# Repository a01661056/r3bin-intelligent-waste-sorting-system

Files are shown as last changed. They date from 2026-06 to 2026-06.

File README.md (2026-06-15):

# R3Bin: Intelligent Waste Sorting System








R3Bin is a complete physical prototype designed to automate waste classification through embedded control, local computer vision, real-time actuation, and custom mechanical sorting. It identifies, sorts, and stores waste objects by integrating an ATmega16 real-time controller, a Raspberry Pi 5 computer-vision subsystem, TensorFlow Lite image classification, UART communication, I2C/TWI communication, EEPROM persistence, MG996R servo control, NEMA 17 stepper motor positioning, sensors, a custom user interface, and a physical structure manufactured through 3D printing and laser-cut fabrication.

R3Bin is not a simulation, mockup, or CAD-only concept. It combines embedded firmware, computer vision, AI inference, mechanical design, manufacturing, real-time control, and hardware/software integration into a functioning system that was built, assembled, calibrated, tested, and demonstrated as a working prototype.

**Demo:** [R3Bin final demo video](https://youtu.be/eC5EfTwEhFM)

## Technologies

| Domain | Technologies |
| --- | --- |
| Embedded control | ATmega16, AVR-GCC, direct register-level C firmware, GPIO, ADC |
| Computer vision | Raspberry Pi 5, Logitech C270 webcam, OpenCV |
| AI inference | TensorFlow Lite / LiteRT, Teachable Machine exported model |
| Communication | UART serial protocol, I2C/TWI bus |
| Persistence | ATmega16 EEPROM for game high score and per-category statistics |
| Actuation | PCA9685 PWM driver, MG996R servos, NEMA 17 stepper motor |
| Motor control | DRV8825 stepper driver, KW11 homing switch, calibrated sector positioning |
| User interface | 16x2 LCD, category LEDs, potentiometer, push buttons, active buzzer |
| Mechanical design | ForgeCAD, 3D printing, laser-cut PVC/acrylic, PETG/PLA parts, styrene dividers |

## Project Visuals

### Complete Physical Prototype

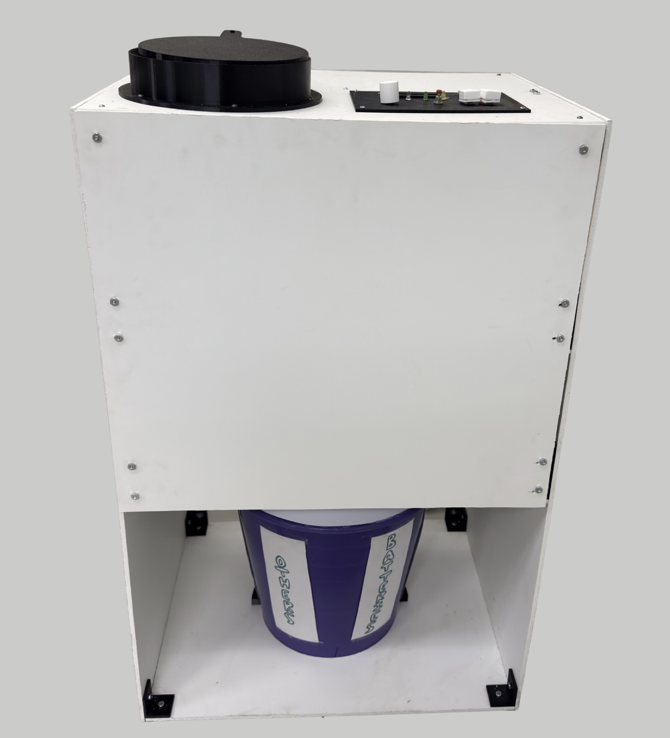
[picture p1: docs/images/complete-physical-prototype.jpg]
Complete physical R3Bin prototype


Complete assembled R3Bin prototype with the user-facing interface, inlet mechanism, PVC/acrylic structure, and storage body.

### Internal Mechanism Through Acrylic

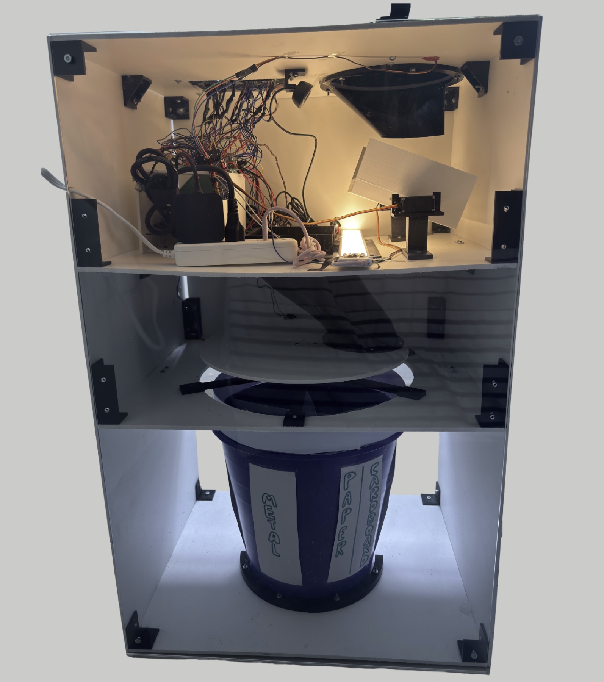
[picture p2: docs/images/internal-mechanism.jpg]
Internal R3Bin mechanism through acrylic


Rear acrylic view showing the internal sorting path, actuation mechanisms, rotating disk area, and storage region.

### Waste Sorting Process

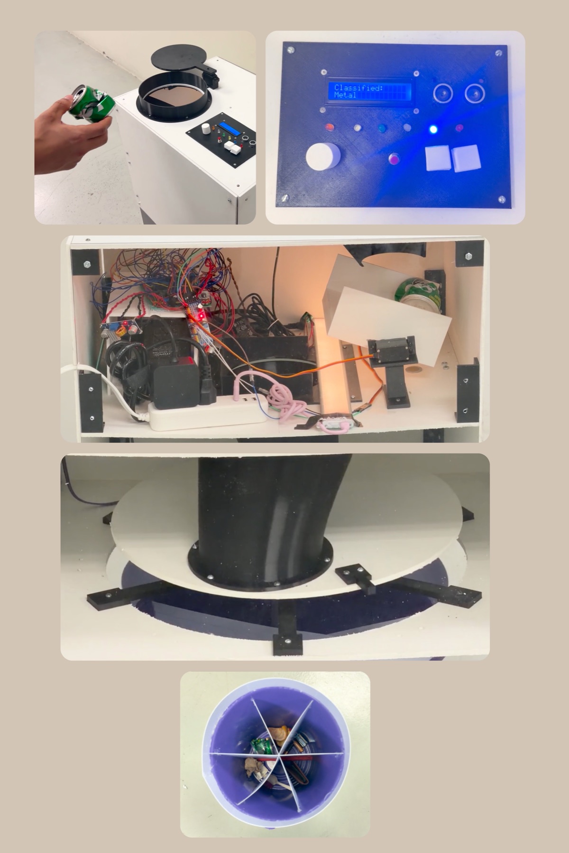
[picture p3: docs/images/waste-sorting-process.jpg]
R3Bin waste sorting process collage


End-to-end sorting sequence from object insertion and photo booth capture to classification, disk positioning, and storage.

### User Interface and Embedded Control

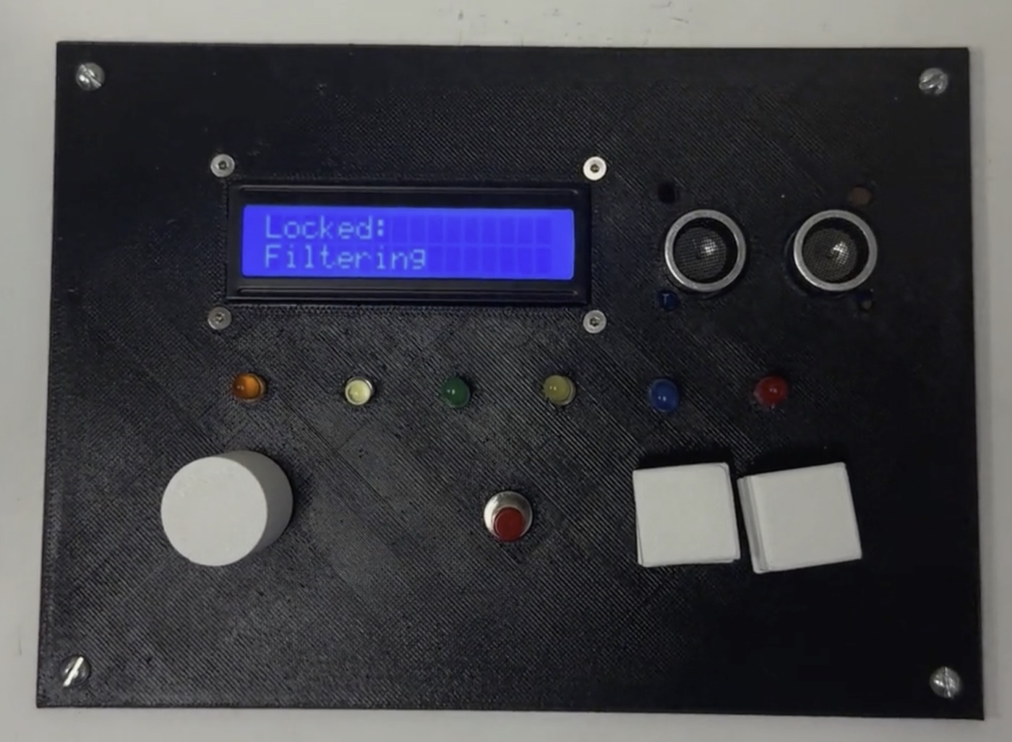
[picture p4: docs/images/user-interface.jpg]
R3Bin user interface


User-facing control panel with LCD feedback, mode selector, category LEDs, buttons, and ultrasonic detection.

### CAD Model vs Physical Build

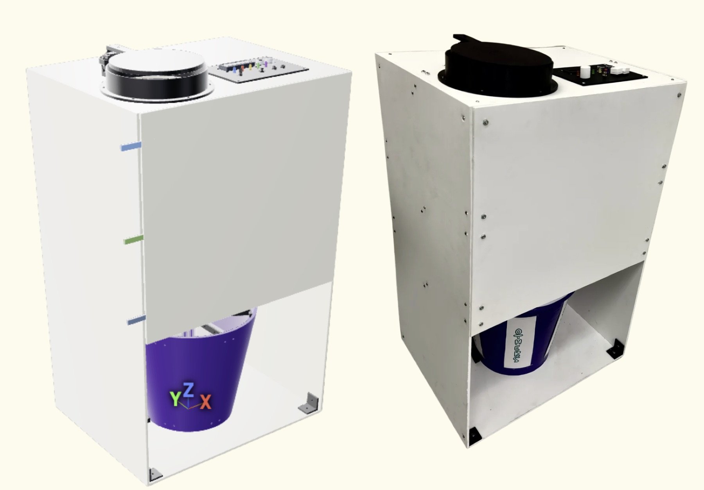
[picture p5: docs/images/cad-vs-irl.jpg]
R3Bin CAD model vs physical build


ForgeCAD model compared with the final physical prototype, showing the transition from parametric design to manufactured system.

## Overview

R3Bin automates the full waste-sorting cycle:

1. A user selects an operating mode with a potentiometer.
2. An ultrasonic sensor detects the user's hand and locks the selected mode.
3. A servo-driven inlet lid opens and receives one object.
4. The object enters an internal photo booth.
5. The ATmega16 requests image classification from the Raspberry Pi 5 over UART.
6. The Raspberry Pi captures an image with a Logitech C270 webcam and runs a TensorFlow Lite model locally.
7. The Raspberry Pi returns the detected category to the ATmega16.
8. The ATmega16 drives the NEMA 17 sorting disk to the selected sector.
9. Servo mechanisms release the object into the matching storage compartment.
10. EEPROM-backed counters and game high score are updated.

The final prototype classifies waste into six categories:

- Other
- Plastic
- Paper/cardboard
- Metal
- Organic
- Batteries

## Key Contributions

- Built a complete hardware/software system combining embedded firmware, AI inference, mechanisms, and physical manufacturing.
- Implemented real-time control logic on an ATmega16 using C, direct register configuration, UART, I2C/TWI, ADC, EEPROM, GPIO, and timing routines.
- Integrated Raspberry Pi 5 computer vision using OpenCV, TensorFlow Lite, and a locally trained Teachable Machine model.
- Designed and calibrated actuator sequences for MG996R servos, a PCA9685 PWM driver, a NEMA 17 stepper motor, and a DRV8825 stepper driver.
- Developed ForgeCAD parametric models, 3D-printable parts, laser-cut PVC/acrylic layouts, and physical assembly strategy.
- Validated the complete system with timing, energy, capacity, and classification measurements.

## My Role

My primary contributions focused on embedded systems integration, firmware architecture, hardware interfacing, and system-level integration. I worked on connecting the ATmega16 controller, Raspberry Pi vision subsystem, communication interfaces, and electromechanical sorting mechanisms into a complete working prototype. A major part of my work was making the independent subsystems operate together reliably as a single physical system.

This included work on UART communication, I2C/TWI communication, ATmega16 firmware, EEPROM persistence, operating-mode logic, actuator control, sensor integration, testing, debugging, calibration, and system-level integration between the microcontroller, Raspberry Pi, computer vision subsystem, and mechanical mechanisms.

Specific areas of ownership included:

- ATmega16 firmware structure and mode-state logic.
- UART protocol between ATmega16 and Raspberry Pi.
- PCA9685 servo control through I2C/TWI.
- EEPROM persistence for statistics and game high score.
- Potentiometer mode selection through ADC.
- LCD/LED user-feedback logic.
- NEMA 17 homing and sector positioning with the KW11 switch.
- Physical calibration of servos, disk movement, object release, and timing.
- Integration testing across firmware, camera classification, motors, and mechanical structure.

## Collaboration

R3Bin was developed as a team project rather than a solo build.

Team members:

- Ricardo Morán Ávila
- Joaquín Ruenes Hernández
- Rafael Tello Arenas

All team members contributed to the final prototype across design, manufacturing, assembly, testing, documentation, and demonstration.

## System Architecture

R3Bin separates responsibilities across real-time control, AI inference, user interaction, and mechanical execution.

| Subsystem | Responsibility |
| --- | --- |
| ATmega16 real-time controller | Main state machine, mode logic, actuator sequencing, LCD/LED updates, EEPROM storage, sensor polling |
| Raspberry Pi 5 vision subsystem | Camera capture, TensorFlow Lite inference, label normalization, UART response |
| TensorFlow Lite classification pipeline | Local image classification into six waste categories plus no-object detection |
| UART communication layer | Request/response protocol between ATmega16 and Raspberry Pi |
| PCA9685 servo subsystem | PWM generation for MG996R servo actuators through I2C/TWI |
| DRV8825 stepper subsystem | Step/direction control for NEMA 17 disk positioning |
| LCD/LED user interface | Mode feedback, classification result, score/stats display, category indication |
| EEPROM persistence | Stores high score and per-category object counts after power loss |
| Mechanical sorting structure | Laser-cut PVC/acrylic body, printed mechanisms, rotating disk, photo booth, bucket storage |

## Validation Results

| Metric | Result |
| --- | ---: |
| Average boot time | 6.18 s |
| Average Raspberry Pi boot time | 10.02 s |
| Average classification time | 2.18 s |
| Average full sorting cycle time | 13.56 s |
| Overall classification accuracy | 80% |
| Maximum object size | 8 cm x 8 cm x 8 cm |
| Maximum object weight | 300 g |
| Minimum object weight | 5 g |
| Total storage capacity | 15 L |
| Capacity per compartment | 2.5 L |
| Peak measured consumption | 26.6 VA / 17.5 W |

Classification validation reported in the final presentation:

| Category | Correct / Tested |
| --- | ---: |
| Plastic | 10 / 10 |
| Paper/cardboard | 8 / 10 |
| Metal | 8 / 10 |
| Organic | 8 / 10 |
| Batteries | 6 / 10 |

## Hardware Stack

- ATmega16 microcontroller
- Raspberry Pi 5
- Logitech C270 USB webcam
- PCA9685 16-channel PWM servo driver
- MG996R servo motors
- NEMA 17 17HS4023 stepper motor
- DRV8825 stepper motor driver
- KW11 limit switch for disk homing
- HC-SR04 ultrasonic sensor
- 16x2 parallel LCD
- Category LEDs, active buzzer, potentiometer, and push buttons
- 12 V / 5 A AC/DC supply with step-down conversion for 5 V subsystems
- 5 mm foamed PVC structure
- Acrylic rear panel
- PETG/PLA 3D printed parts
- Manually cut 30 pt styrene divider sheets for final bucket compartments

## Software Stack

- C firmware for ATmega16
- AVR-GCC toolchain and Makefile-based builds
- Direct register-level peripheral control
- UART serial protocol
- I2C/TWI driver for PCA9685
- EEPROM storage through AVR libraries
- Python on Raspberry Pi 5
- OpenCV camera capture
- TensorFlow Lite / LiteRT inference
- Teachable Machine model export
- ForgeCAD parametric CAD scripts

## Operating Modes

### Stats Mode

Stats Mode displays the number of classified objects stored in each category. Counts are saved in EEPROM and survive power loss. A button can reset the stored counts after the bins are emptied.

### Filtering Mode

Filtering Mode performs the standard automatic classification cycle. It opens the lid, captures an image, receives the AI category, rotates the disk to the correct sector, releases the object, updates the corresponding count, and returns to idle.

### Game Mode

Game Mode adds an educational interaction layer. The system asks the user to insert a specific category using LEDs and LCD prompts. The Raspberry Pi classifies the inserted object, the ATmega16 checks whether it matches the requested category, and the game score/high score are updated in EEPROM.

## Firmware Architecture

The main firmware is implemented in [`firmware/atmega16.c`](firmware/atmega16.c). It is structured around a polling-based state machine rather than an RTOS.

Core firmware responsibilities:

- Hardware initialization
- LCD messaging
- Potentiometer-based mode selection
- Ultrasonic hand detection
- Servo sequencing through PCA9685
- UART request/response communication with Raspberry Pi
- NEMA 17 homing and sector positioning
- Category LED indication
- EEPROM high-score and statistics storage
- Game-mode scoring logic
- Stats-mode display and reset logic

Focused hardware test programs were used during development for UART, LCD, I2C/PCA9685, KW11, NEMA calibration, and servo-channel validation. This repository keeps only the final working firmware source in `firmware/atmega16.c`.

## Computer Vision Pipeline

The Raspberry Pi script is implemented in [`raspberry/r3bin_uart_camera_capture.py`](raspberry/r3bin_uart_camera_capture.py).

Pipeline:

1. Wait for `CAPTURE` over `/dev/serial0`.
2. Capture a frame from the Logitech C270 webcam.
3. Preprocess the image for the TensorFlow Lite model input size and dtype.
4. Run local inference.
5. Normalize the output label into the ATmega16 category protocol.
6. Return the result over UART.

If confidence is below the selected threshold, the object is classified as `OTHER` unless the model explicitly detects `NO_OBJECT`.

## Communication Protocols

### ATmega16 to Raspberry Pi UART

- Baud rate: 9600
- ATmega16 TX to Raspberry Pi RX uses a voltage divider.
- Raspberry Pi TX to ATmega16 RX is connected directly.
- Both systems share common ground.

Messages:

```text
ATmega16 -> Raspberry Pi: CAPTURE
Raspberry Pi -> ATmega16: METAL | ORGANIC | PAPER | PLASTIC | BATTERIES | OTHER | NO_OBJECT
```

### ATmega16 to PCA9685 I2C/TWI

- I2C frequency: 100 kHz
- PCA9685 servo PWM frequency: 50 Hz
- Used to drive MG996R servo channels for the inlet lid and photo booth mechanism.

### ATmega16 to DRV8825

- STEP/DIR/ENABLE control from GPIO pins.
- KW11 switch provides the disk home reference.
- Physical sector positions were calibrated experimentally.

## Mechanical Design

The physical structure is a vertical rectangular bin approximately 500 mm wide, 400 mm deep, and 800 mm tall.

Mechanical features:

- Laser-cut 5 mm PVC body panels
- Transparent acrylic rear panel for viewing the internal process
- Servo-driven inlet lid
- Internal photo booth for stable image capture
- Rotating disk and guide path for sorting
- NEMA 17 support hub and receiver socket
- Custom printed holders, collars, supports, brackets, and guides
- Removable bucket divided into six compartments
- Final bucket divisions made with manually cut styrene sheets for simplicity and reduced material use

ForgeCAD was used to design and iterate the physical structure, validate clearances, generate print kits, and produce manufacturing layouts.

## Engineering Challenges

- Stabilizing objects for reliable image capture inside a compact bin volume.
- Coordinating Raspberry Pi inference latency with ATmega16 real-time actuator control.
- Designing a UART protocol robust enough for repeated physical testing.
- Calibrating servo motion with real mechanical load and linkage tolerances.
- Calibrating the NEMA 17 disk positioning against asymmetric physical load.
- Debugging shared grounds, reset behavior, UART level shifting, and programmer wiring.
- Reducing PETG usage by replacing overcomplicated printed bucket dividers with manually cut styrene sheets.
- Preserving maintainability while integrating electronics, mechanics, and user interaction in a constrained enclosure.

## Demo

- Final demo video: [https://youtu.be/eC5EfTwEhFM](https://youtu.be/eC5EfTwEhFM)
- Final presentation: [`docs/final-presentation.pdf`](docs/final-presentation.pdf)

The full video is hosted externally so the repository stays lightweight and GitHub-compatible.

## Repository Structure

```text
R3Bin/
├── firmware/       # Final ATmega16 firmware and Makefile
├── raspberry/      # Raspberry Pi vision + UART script, labels, TFLite model
├── forgecad/       # Parametric ForgeCAD model files and CAD reference assets
├── print-kits/     # Exported 3MF files for 3D printed parts
├── manufacturing/  # PVC/acrylic cutting files and laser-cut documentation
├── docs/           # Final presentation and technical documentation
└── README.md       # Portfolio overview
```

## Build and Run

Firmware build example:

```bash
cd firmware
make compile FILE=atmega16.c
make program FILE=atmega16.c
```

Raspberry Pi vision service example:

```bash
python3 raspberry/r3bin_uart_camera_capture.py
```

ForgeCAD model:

```bash
forgecad run forgecad/smart-bin-layout.forge.js
```

## Notes

The final physical prototype uses manually cut styrene dividers inside the bucket. Some ForgeCAD print kits represent earlier mechanical iterations and are preserved to document the engineering process, but they were not all used in the final assembly.

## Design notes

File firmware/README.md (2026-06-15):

# Firmware

This folder contains the final ATmega16 firmware used by the physical R3Bin
prototype.

## Main File

- `atmega16.c`: final integrated firmware for R3Bin.

## Build

```bash
make compile FILE=atmega16.c
```

## Program

```bash
make program FILE=atmega16.c
```

Default target settings:

- MCU: ATmega16
- Clock: 8 MHz
- Programmer: USBasp

## Notes

The firmware uses direct AVR register access and polling-based control. The project intentionally keeps the ATmega16 responsible for real-time actuator sequencing while the Raspberry Pi handles image classification.

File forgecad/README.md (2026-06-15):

# ForgeCAD Models

This folder contains the parametric ForgeCAD source files used to design and iterate R3Bin.

## Main Model

- `smart-bin-layout.forge.js`: top-level assembly model.

## Key Modules

- `rotating-disk-module.forge.js`: rotating disk, NEMA support, guide path, KW11 reference geometry.
- `bucket-storage-bins.forge.js`: bucket/storage design iteration.
- `printed-structure-brackets.forge.js`: structural brackets.
- `pvc-cut-layout.forge.js`: PVC cutting layout.
- `styrene-cut-layout.forge.js`: styrene cutting reference.

## Run

```bash
forgecad run smart-bin-layout.forge.js
```

## Note

Some ForgeCAD-generated print kits document earlier design iterations. The final physical bucket uses manually cut styrene dividers rather than the printed bucket divider structures.

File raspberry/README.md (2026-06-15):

# Raspberry Pi Vision Subsystem

This folder contains the Raspberry Pi script and model files used for local waste classification.

## Files

- `r3bin_uart_camera_capture.py`: UART + camera + TensorFlow Lite inference loop.
- `model_unquant.tflite`: exported Teachable Machine TensorFlow Lite model.
- `labels.txt`: model label file.

## Runtime Behavior

The script waits for the ATmega16 to send:

```text
CAPTURE
```

It then captures an image from the Logitech C270 webcam, runs TensorFlow Lite inference, normalizes the label, and responds with one of:

```text
METAL
ORGANIC
PAPER
PLASTIC
BATTERIES
OTHER
NO_OBJECT
```

## Expected Raspberry Pi Paths

The final deployment expected:

```text
~/r3bin/model/model_unquant.tflite
~/r3bin/model/labels.txt
~/r3bin/captures/
```

The script stores timestamped captures for debugging and dataset improvement.

## Run

```bash
python3 r3bin_uart_camera_capture.py
```

## Dependencies

- Python 3
- OpenCV
- NumPy
- pyserial
- ai-edge-litert or tflite-runtime

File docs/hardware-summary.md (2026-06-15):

# Hardware Summary

This document summarizes the main hardware architecture used in the final R3Bin prototype.

## Main Controllers

- **ATmega16:** real-time control, mode logic, actuators, LCD/LED UI, EEPROM, sensors.
- **Raspberry Pi 5:** local computer vision inference with TensorFlow Lite.

## Main Actuators

- **MG996R servos:** inlet lid and photo booth/drop mechanism.
- **PCA9685:** 16-channel PWM driver controlled from ATmega16 through I2C/TWI.
- **NEMA 17 stepper motor:** sorting disk positioning.
- **DRV8825:** stepper driver.

## Main Sensors and Inputs

- **HC-SR04 ultrasonic sensor:** detects user/hand presence.
- **KW11 limit switch:** home reference for rotating disk.
- **Potentiometer:** operating-mode selector.
- **Push buttons:** game high-score reset and stats-count reset.
- **Logitech C270 webcam:** image input for Raspberry Pi classification.

## User Interface

- 16x2 parallel LCD.
- Six category LEDs.
- Active buzzer.
- Potentiometer selector.
- Reset and mode-specific buttons.

## UART Protocol

```text
ATmega16 -> Raspberry Pi: CAPTURE
Raspberry Pi -> ATmega16: METAL | ORGANIC | PAPER | PLASTIC | BATTERIES | OTHER | NO_OBJECT
```

## Voltage Divider

The ATmega16 TX line is 5 V logic and the Raspberry Pi RX line is 3.3 V logic. The final test divider used:

- R1: 1.9 kOhm from ATmega16 TX to midpoint.
- R2: 3.3 kOhm from midpoint to GND.
- Midpoint: Raspberry Pi RX.
- Raspberry Pi TX to ATmega16 RX is direct.
- Common GND is required.

## ADC Reference

The potentiometer is read on PA0 / ADC0. The firmware uses AVCC as the ADC reference and a small capacitor on AREF to ground for reference-noise filtering.

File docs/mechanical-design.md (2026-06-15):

# Mechanical Design

R3Bin was designed as a vertically organized physical prototype with distinct functional levels.

## Structure

- Approximate outer dimensions: 500 mm x 400 mm x 800 mm.
- Main panels: 5 mm foamed PVC.
- Rear panel: transparent acrylic for process visibility.
- Assembly: screws, nuts, and printed brackets/supports.

## Functional Levels

- **Level 0:** user interface, inlet opening, automatic lid.
- **Level 1:** photo booth and image-capture region.
- **Level 2:** rotating disk, NEMA 17 motor, guide/funnel path.
- **Level 3:** removable bucket with six manually divided compartments.

## Final Bucket Design

The final physical bucket uses manually cut 30 pt styrene sheets to create six internal compartments. Earlier ForgeCAD designs included printed divider hubs, rails, and bridge structures, but those were not used in the final physical prototype because they were less simple and required more printed material.

This design decision reduced PETG usage, simplified assembly, and made the bucket easier to maintain.

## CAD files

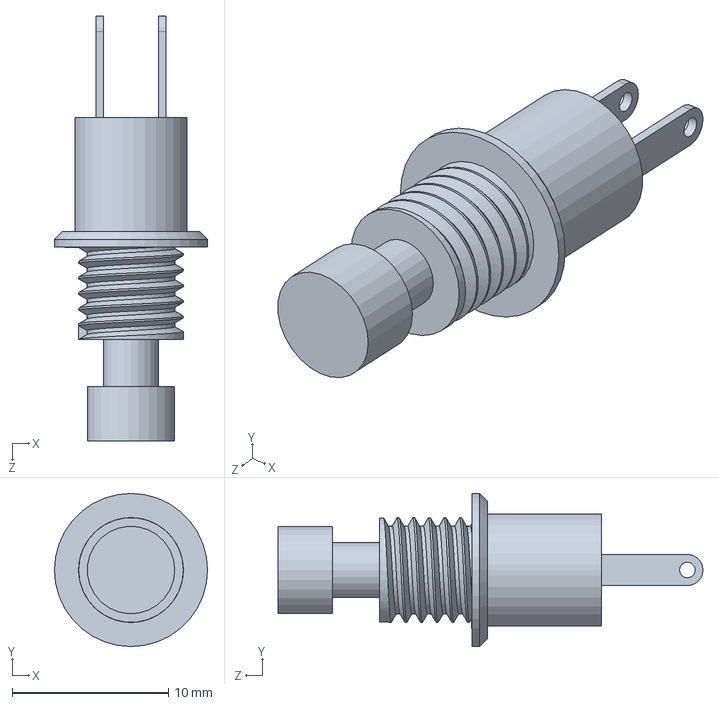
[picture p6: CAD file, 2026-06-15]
forgecad/assets/PBS-110-DC177-Push-button-Main-part.SLDPRT
9.80 x 9.80 x 27.2 mm

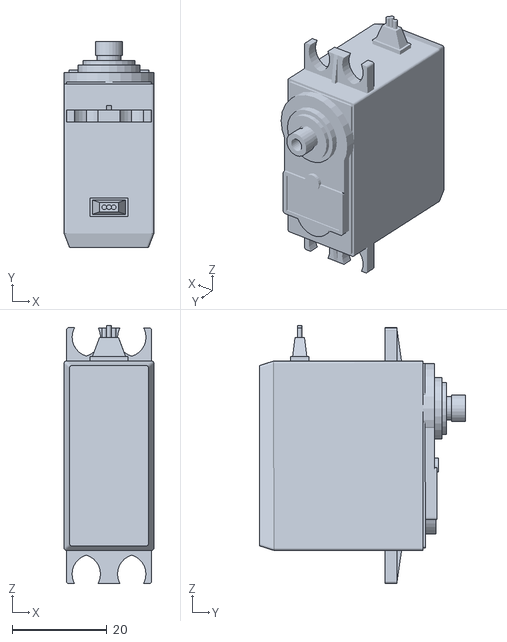
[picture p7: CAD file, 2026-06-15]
forgecad/assets/MG996R_Servo_Model_parts/part_01.obj
19.0 x 43.5 x 54.5

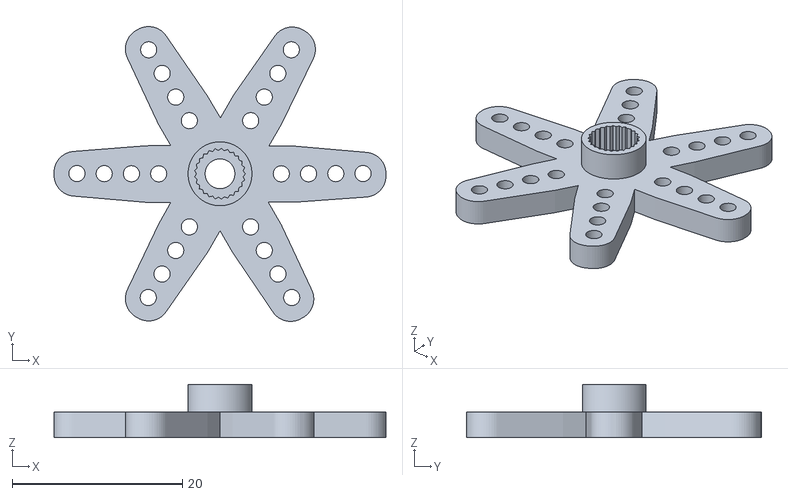
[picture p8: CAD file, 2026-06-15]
forgecad/assets/ServoMotor_Arms_MG996R_parts/horn_2.obj
39.0 x 34.6 x 6.26

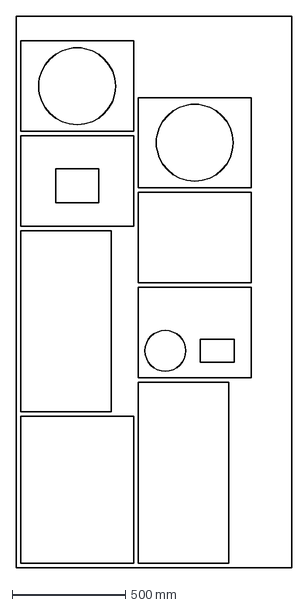
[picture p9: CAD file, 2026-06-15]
manufacturing/PVC_Layout_R3.DXF
1220.0 x 2440.0 mm

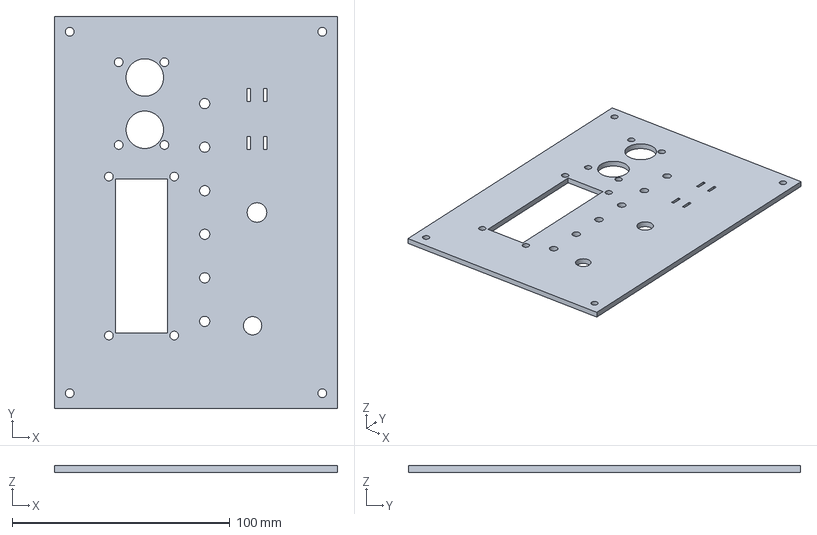
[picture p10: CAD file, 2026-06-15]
print-kits/level0-ui-cover-plate.3mf
130.0 x 180.0 x 3.00 mm

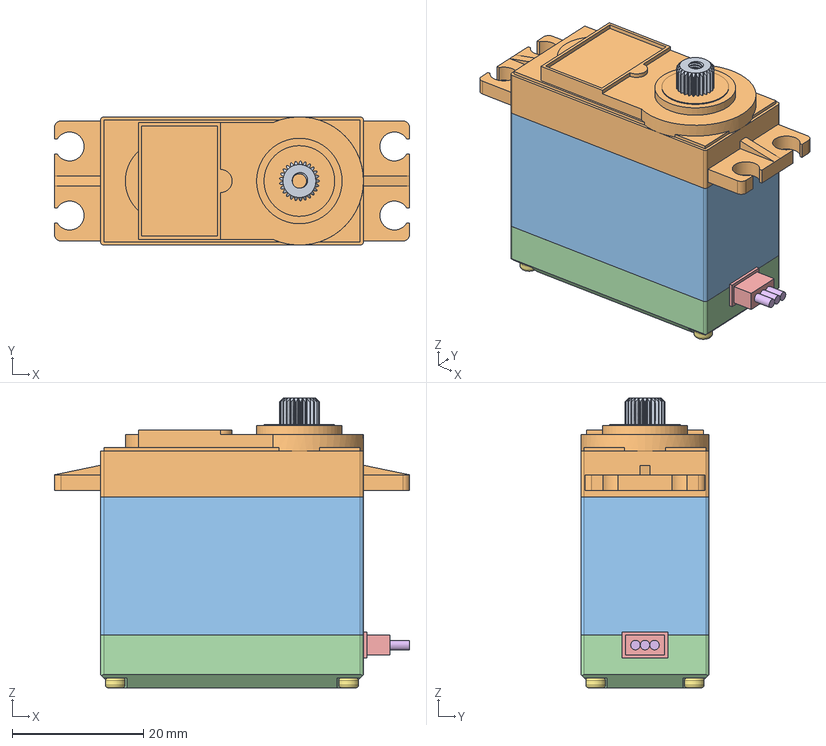
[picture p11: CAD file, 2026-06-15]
forgecad/assets/mg996r-v17.step
54.0 x 19.5 x 44.0 mm

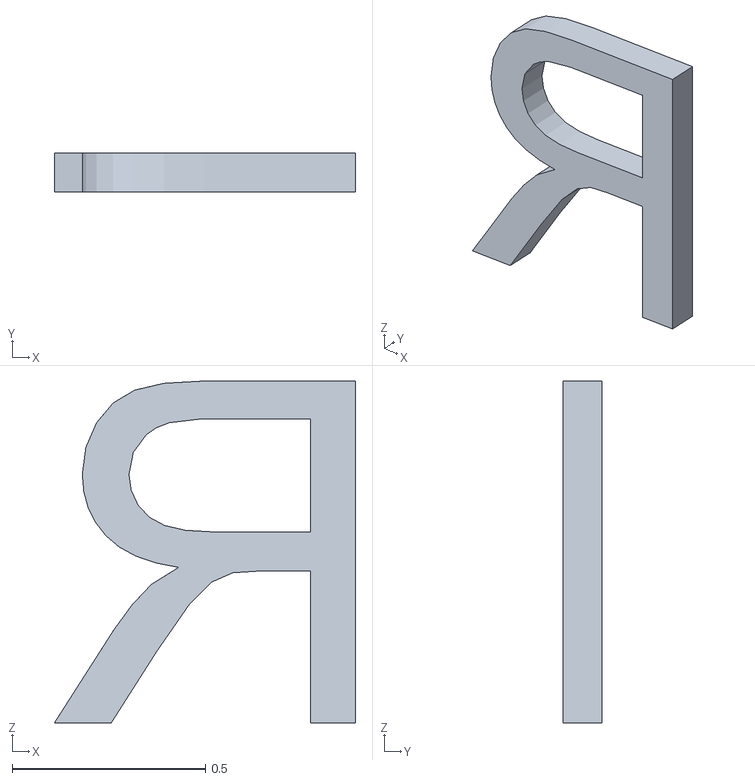
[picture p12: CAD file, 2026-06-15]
forgecad/assets/MG996R_Servo_Model_parts/part_14.obj
0.78 x 0.1 x 0.885

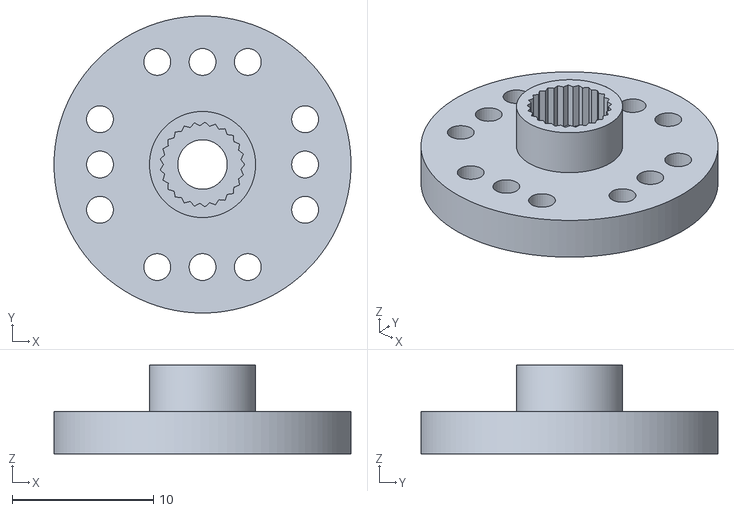
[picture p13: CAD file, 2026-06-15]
forgecad/assets/ServoMotor_Arms_MG996R_parts/horn_1.obj
21.0 x 21.0 x 6.26

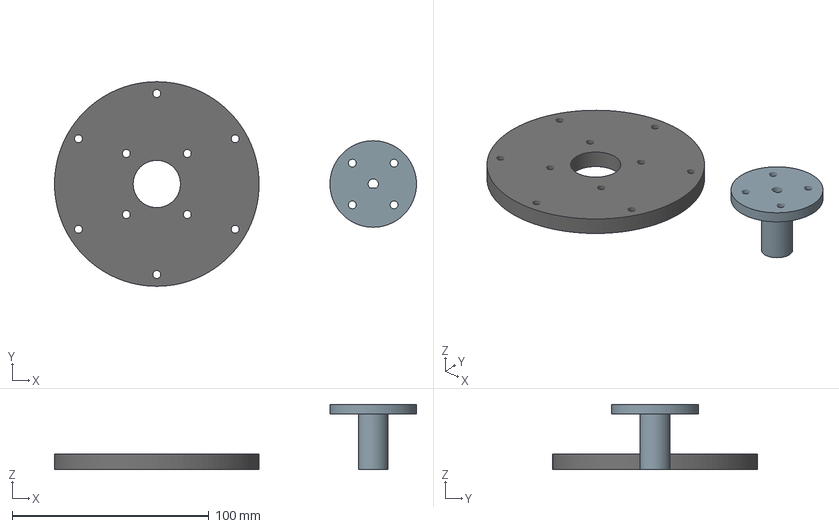
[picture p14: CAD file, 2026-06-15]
print-kits/level2-motor-hub-receiver.3mf
184.0 x 104.0 x 33.2 mm
PETG centered NEMA17 motor support hub for reprinted spider arms
PETG NEMA17 D-shaft receiver socket - 5.2mm D bore

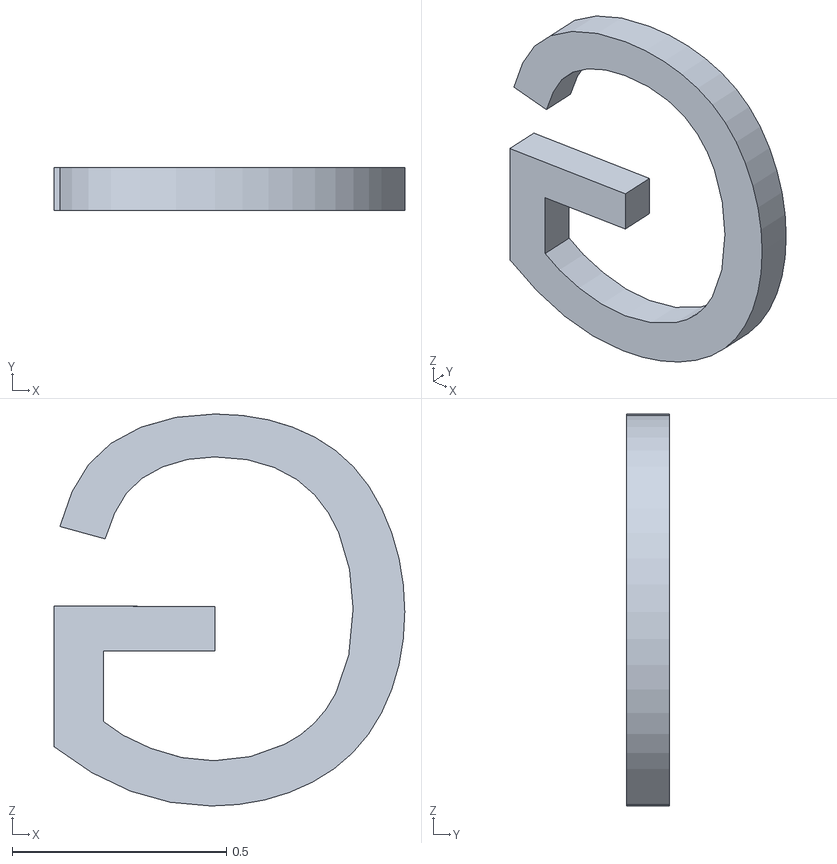
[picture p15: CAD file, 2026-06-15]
forgecad/assets/MG996R_Servo_Model_parts/part_08.obj
0.819 x 0.1 x 0.915

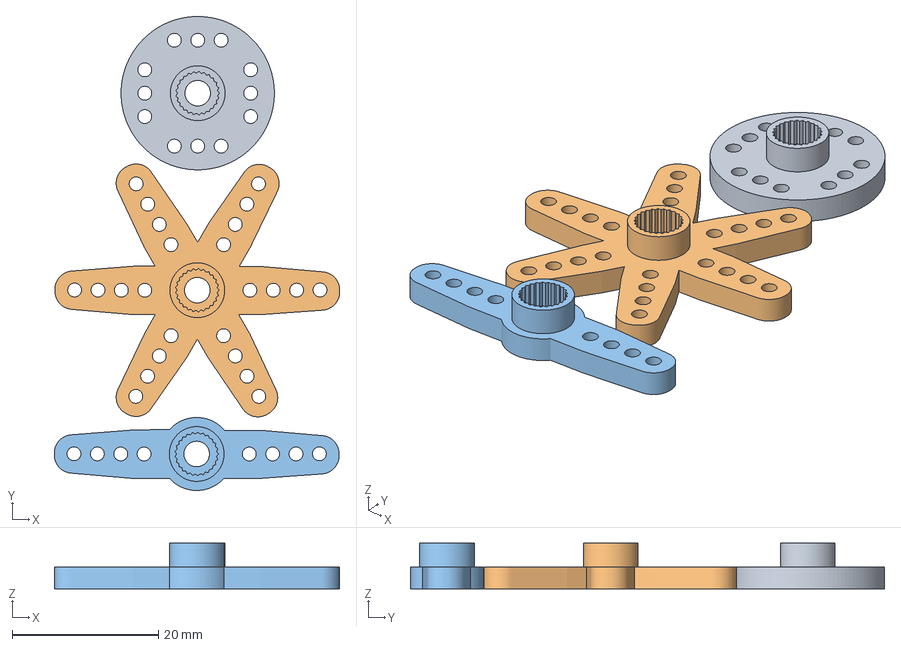
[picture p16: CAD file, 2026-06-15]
forgecad/assets/ServoMotor_Arms_MG996R.3mf
39.1 x 64.9 x 6.26 mm
ServoMotor Arms.stl_B
ServoMotor Arms.stl_A_A
ServoMotor Arms.stl_A_B

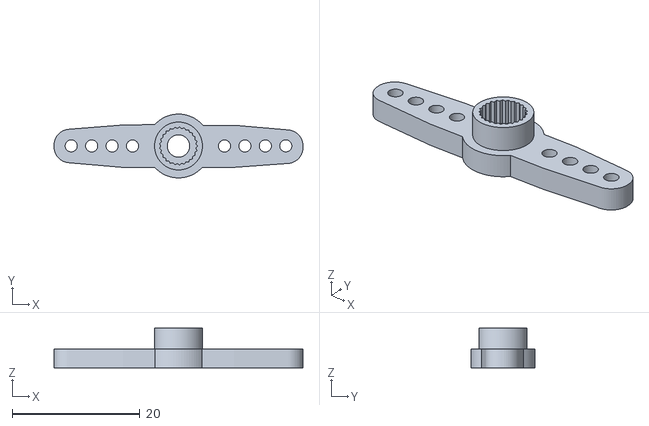
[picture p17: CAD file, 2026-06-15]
forgecad/assets/ServoMotor_Arms_MG996R_parts/horn_3.obj
39.0 x 10.00 x 6.26

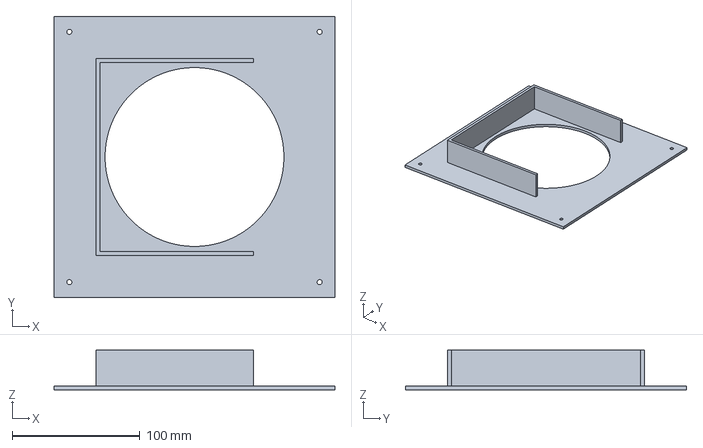
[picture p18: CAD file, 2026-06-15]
print-kits/floor-collar-circular-opening.3mf
220.0 x 220.0 x 31.0 mm

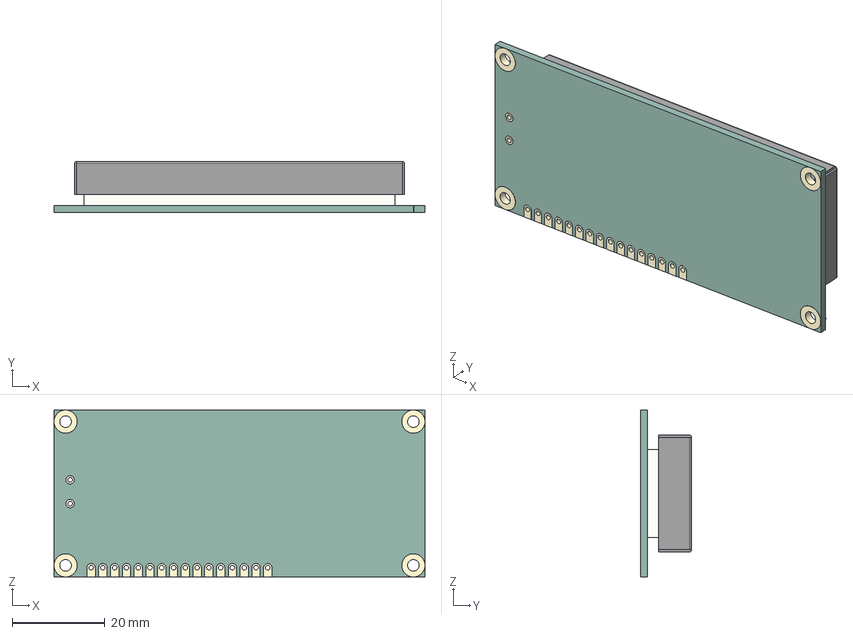
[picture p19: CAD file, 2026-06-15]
forgecad/assets/LCD-Displaytech-162J.step
80.0 x 11.1 x 36.0 mm

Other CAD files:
forgecad/assets/MG996R_Servo_Model_parts/part_09.obj
print-kits/camera-sensor-holders.3mf
forgecad/assets/c270tripod.stl
forgecad/assets/MG996R_Servo_Model_parts/part_05.obj
forgecad/assets/HC-SR04-Sensor.3mf
forgecad/assets/HC-SR04-Sensor.stl
forgecad/assets/HC-SR04-Sensor.stp
forgecad/assets/LCD-Displaytech-162J.stl
forgecad/assets/MG996R_Servo_Model.obj
forgecad/assets/MG996R_Servo_Model_parts/part_02.obj
forgecad/assets/MG996R_Servo_Model_parts/part_03.obj
forgecad/assets/MG996R_Servo_Model_parts/part_04.obj
forgecad/assets/MG996R_Servo_Model_parts/part_06.obj
forgecad/assets/MG996R_Servo_Model_parts/part_07.obj
forgecad/assets/MG996R_Servo_Model_parts/part_10.obj
forgecad/assets/MG996R_Servo_Model_parts/part_11.obj
forgecad/assets/MG996R_Servo_Model_parts/part_12.obj
forgecad/assets/MG996R_Servo_Model_parts/part_13.obj
forgecad/assets/MG996R_Servo_Model_parts/part_15.obj
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

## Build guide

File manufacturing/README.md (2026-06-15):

# Manufacturing Files

This folder contains fabrication references for the physical R3Bin prototype.

## Files

- `PVC_Layout_R3.DXF`: cutting layout for PVC panels.
- `Cortes PVC 5mm.pdf`: cutting reference/specification document.

## Materials

- 5 mm foamed PVC for the main body.
- Acrylic rear panel for process visibility.
- PETG/PLA printed mechanisms and structural parts.
- 30 pt styrene sheets manually cut for bucket divisions.

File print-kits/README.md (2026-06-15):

# 3D Print Kits

This folder contains exported `.3mf` print kits for the physical prototype.

Examples:

- `level0-ui-cover-plate.3mf`
- `photo-booth-tray.3mf`
- `servo-holders.3mf`
- `level2-motor-hub-receiver.3mf`
- `level2-socket-hub-arms.3mf`
- `kw11-trigger-and-prism.3mf`
- `structure-brackets_long.3mf`
- `structure-brackets_short.3mf`

## Final Prototype Note

The final bucket compartments were made from manually cut styrene sheets. Any bucket-divider print kits from earlier iterations should be treated as design history rather than the final physical storage solution.

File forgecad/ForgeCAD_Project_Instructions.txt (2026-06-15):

R3Bin ForgeCAD Project Instructions
===================================

1. How to open the project in ForgeCAD
-------------------------------------

Open Terminal, go to the folder that contains the ForgeCAD files, and run:

  npx forgecad dev

If you are still inside the original project folder and want to use the local
installed ForgeCAD tools, you can also run:

  ./.tools/node_modules/.bin/forgecad dev

ForgeCAD will start a local server and show a URL similar to:

  http://127.0.0.1:5173

Open that URL in the browser and select the .forge.js file you want to view.

2. Most important model files
-----------------------------

The main model is:

  smart-bin-layout.forge.js

This file imports other files and assets, so these should stay together in the
same folder structure:

  smart-bin-layout.forge.js
  rotating-disk-module.forge.js
  bucket-storage-bins.forge.js
  printed-structure-brackets.forge.js
  c270tripod-hole-edit.forge.js
  fc51-holder-box-edit.forge.js
  pvc-cut-layout.forge.js
  styrene-cut-layout.forge.js
  assets/

Do not move only smart-bin-layout.forge.js by itself. The imports are relative,
so the other .forge.js files and the assets folder must move with it.

3. Important print kit files
----------------------------

Useful final print kits include:

  print-kit-level0-ui-cover-plate.3mf
  print-kit-level0-blank-cover-plate.3mf
  print-kit-lid-with-stick.3mf
  print-kit-photo-booth-tray.3mf
  print-kit-servo-holders.3mf
  print-kit-raised-inlet-collar.3mf
  print-kit-level1-inlet-collar-slide.3mf
  print-kit-floor-collar-circular-opening.3mf
  print-kit-level2-tall-funnel.3mf
  print-kit-kw11-trigger-and-prism.3mf
  print-kit-camera-sensor-holders.3mf
  print-kit-bucket-*.3mf
  level2-socket-hub-arms-print-kit.3mf
  level2-motor-hub-receiver-print-kit.3mf

The corresponding .forge.js files should also be kept if you want to edit or
regenerate the print kits later.

4. How to validate a model
--------------------------

From the project folder, run:

  npx forgecad run smart-bin-layout.forge.js

For a specific print kit:

  npx forgecad run print-kit-photo-booth-tray.forge.js

This checks that the file can load and prints geometry diagnostics.

5. How to export a 3MF
----------------------

Example:

  npx forgecad export 3mf level2-socket-hub-arms-print-kit.forge.js --output level2-socket-hub-arms-print-kit.3mf --quality high

For most final prints, use:

  --quality high

Use 3MF instead of STL when possible because it preserves multiple objects and
object names better.

6. If moving to another folder
------------------------------

Recommended clean folder structure:

  R3Bin_Final_Project/
    ForgeCAD/
      smart-bin-layout.forge.js
      rotating-disk-module.forge.js
      bucket-storage-bins.forge.js
      printed-structure-brackets.forge.js
      c270tripod-hole-edit.forge.js
      fc51-holder-box-edit.forge.js
      pvc-cut-layout.forge.js
      styrene-cut-layout.forge.js
      assets/
    Print_Kits/
    Firmware_ATmega16/
    RaspberryPi_Vision/
    Presentation/
    Video/
    Measurements/

If you move the files outside the current Codex workspace, Codex may not be able
to access them unless you open a new Codex session from the new folder.

7. Firmware and Raspberry files to keep
---------------------------------------

ATmega16 firmware:

  firmware/atmega16.c
  firmware/Makefile

Raspberry Pi vision script:

  r3bin_uart_camera_capture.py

Raspberry Pi model files should be stored on the Pi at:

  ~/r3bin/model/model_unquant.tflite
  ~/r3bin/model/labels.txt

Captured photos are saved to:

  ~/r3bin/captures/

8. Notes
--------

- Keep the assets folder with the ForgeCAD files.
- Keep .forge.js files if you want editable parametric models.
- Keep .3mf files if you only need to print.
- Frozen files are old checkpoints and are optional unless you want history.
- The current main model is smart-bin-layout.forge.js.

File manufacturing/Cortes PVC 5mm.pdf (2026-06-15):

Guía de Corte Lámina 1220mm x 2440mm Trovicel 5mm

Layout general de la lámina

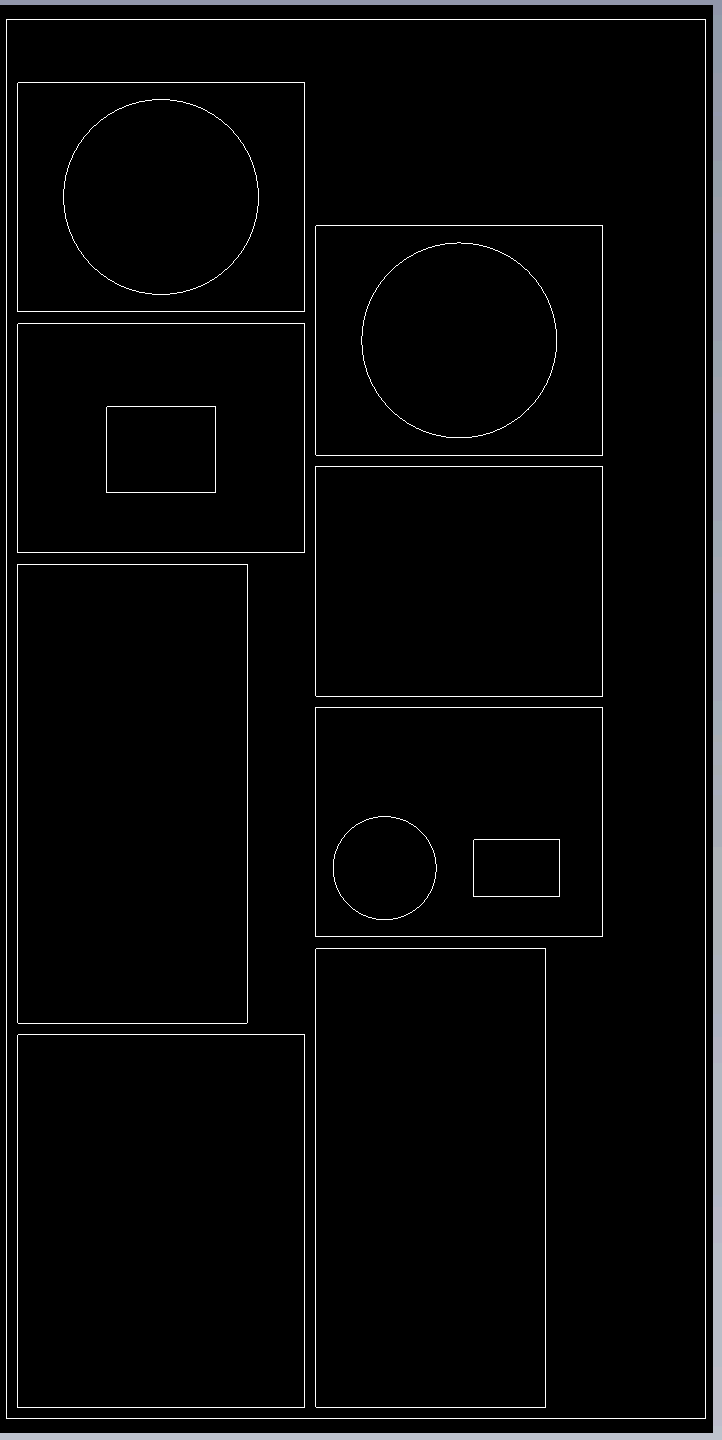
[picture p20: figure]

Figura 1

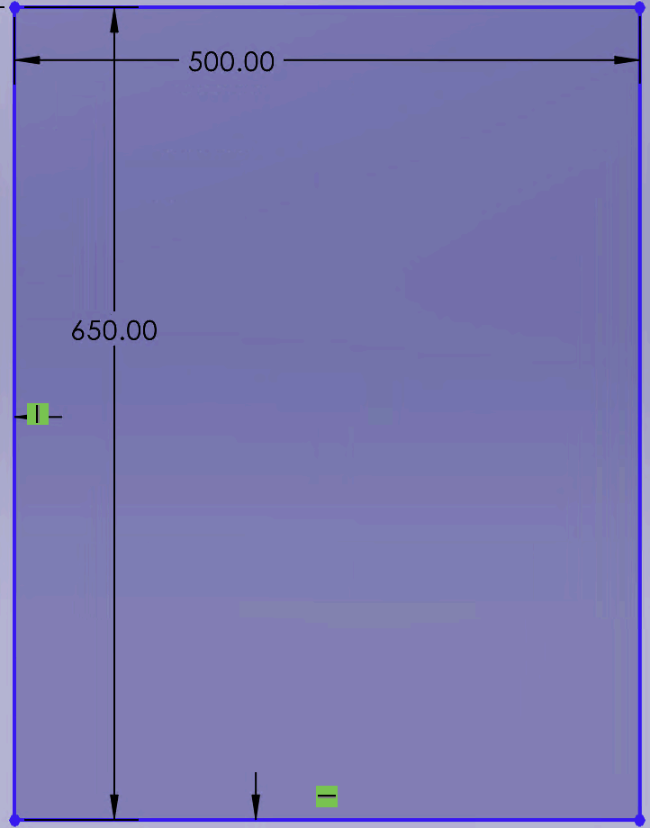
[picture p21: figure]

Rectángulo de 500mm x 650mm

Figura 2

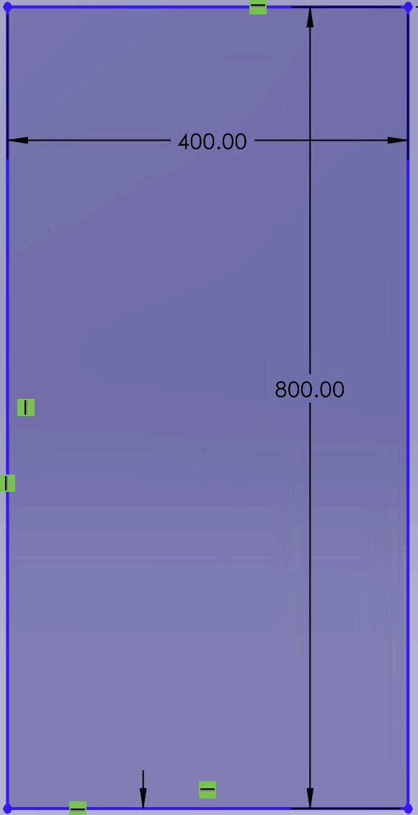
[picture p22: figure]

Rectángulo de 400mm x 800mm

Figura 3

Rectángulo de 400mm x 800mm

Figura 4

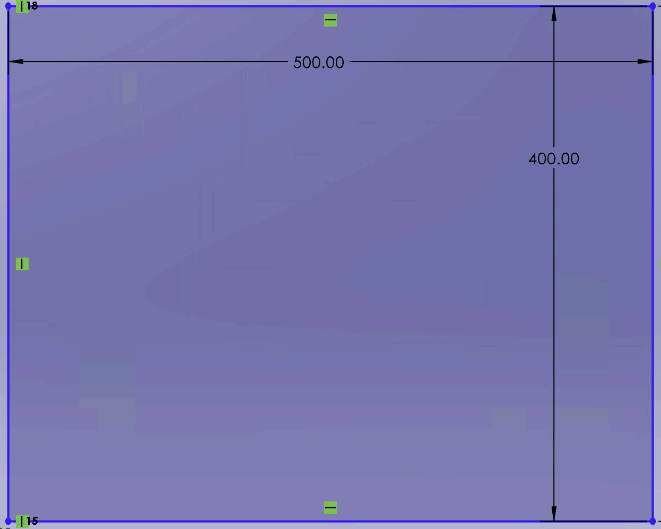
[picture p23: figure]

Rectángulo de 500mm x 400mm

Figura 5

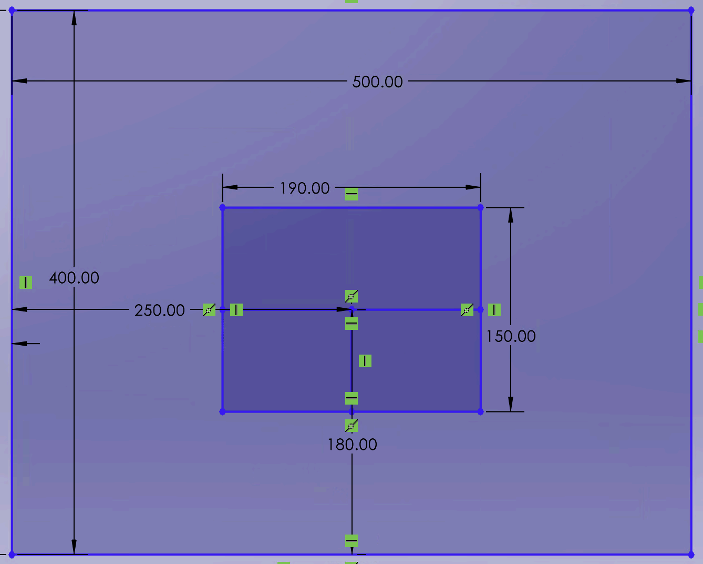
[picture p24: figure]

Rectángulo de 500 mm x 400 mm, con abertura rectangular de 190 mm x 150 mm. La abertura está centrada a 250 mm en X y 180 mm en Y desde la esquina inferior izquierda del panel.

Figura 6

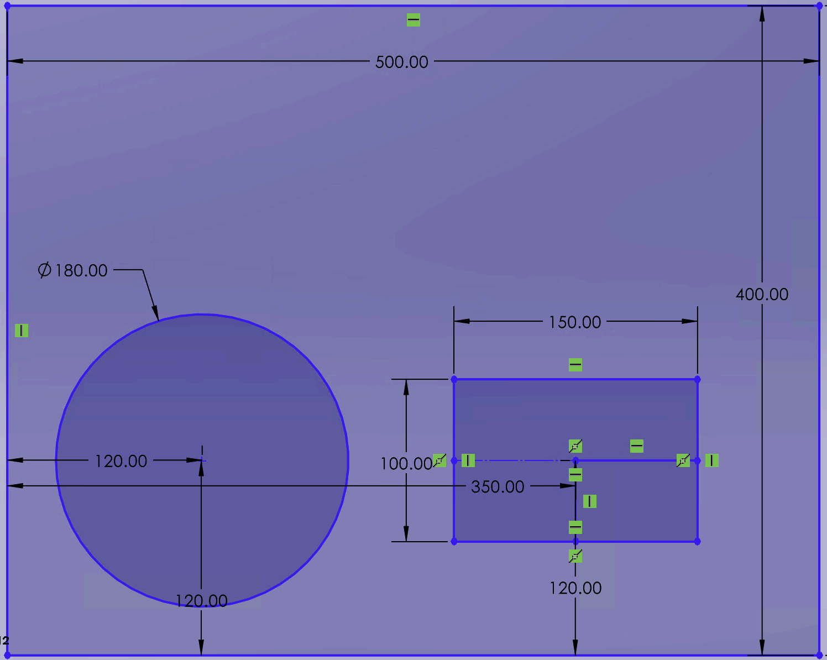
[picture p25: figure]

Rectángulo de 500mm x 400mm, con abertura circular de 180mm de diámetro y abertura rectangular de 150mm x 100mm. La abertura circular está centrada a 120mm en X y 120mm en Y desde la esquina inferior izquierda. La abertura rectangular está centrada a 350mm en X y 120mm en Y desde la esquina inferior izquierda.

Figura 7

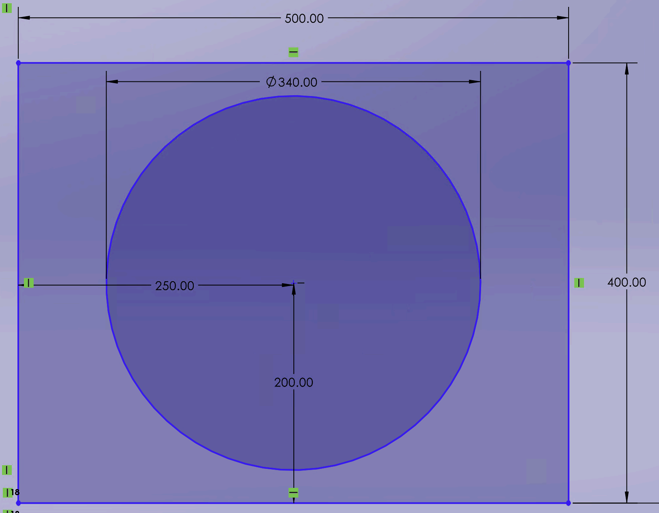
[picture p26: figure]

Rectángulo de 500mm x 400mm, con abertura circular de 340 mm de diámetro. La abertura circular está centrada a 250mm en X y 200mm en Y desde la esquina inferior izquierda del panel.

Figura 8

Rectángulo de 500mm x 400mm, con abertura circular de 340 mm de diámetro. La abertura circular está centrada a 250mm en X y 200mm en Y desde la esquina inferior izquierda del panel.

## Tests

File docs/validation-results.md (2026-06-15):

# Validation Results

The final prototype was evaluated as a complete physical system, not only as a CAD or firmware simulation.

## Timing

| Measurement | Result |
| --- | ---: |
| Average boot time | 6.18 s |
| Average Raspberry Pi boot time | 10.02 s |
| Average classification time | 2.18 s |
| Average full sorting cycle time | 13.56 s |

## Classification

| Category | Correct / Tested |
| --- | ---: |
| Plastic | 10 / 10 |
| Paper/cardboard | 8 / 10 |
| Metal | 8 / 10 |
| Organic | 8 / 10 |
| Batteries | 6 / 10 |

Overall reported accuracy: **40 / 50 = 80%**.

## Physical Limits

| Limit | Value |
| --- | ---: |
| Maximum object size | 8 cm x 8 cm x 8 cm |
| Maximum object weight | 300 g |
| Minimum object weight | 5 g |
| Total storage capacity | 15 L |
| Capacity per compartment | 2.5 L |

## Energy

| State | Apparent Power | Real Power |
| --- | ---: | ---: |
| Initial boot | 15.96 VA | 10.37 W |
| Idle | 18.62 VA | 12.1 W |
| Peak | 26.6 VA | 17.5 W |

Power factor used in the final presentation: **0.65**.

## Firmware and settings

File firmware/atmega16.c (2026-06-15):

#define F_CPU 8000000UL

#include <avr/io.h>
#include <avr/eeprom.h>
#include <avr/pgmspace.h>
#include <stdint.h>
#include <string.h>
#include <util/delay.h>

typedef uint8_t bool;

/* ============================================================
   I2C / TWI DEFINITIONS
   ============================================================ */

#define F_I2C 100000LL

#define TRANSMISSION_SUCCESS -1
#define TRANSMISSION_ERROR   -2

#define MASTER_TRANSMITTER 0
#define MASTER_RECEIVER    1

static bool masterMode;

/* ============================================================
   PCA9685 / SERVO DEFINITIONS
   ============================================================ */

// 0 = skip I2C/PCA9685 and servo commands for diagnostics.
// 1 = complete system behavior with servos driven through the PCA9685.
#define SERVO_SYSTEM_ENABLED 1

#define SERVO0 0x06

#define NEUTRAL_PULSE 1500
#define MAX_PULSE     2600
#define MIN_PULSE     900
#define MAX_ANGLE     90

#define LID_SERVO_CHANNEL            0
#define PHOTO_BOOTH_LEFT_SERVO_CHANNEL   4
#define PHOTO_BOOTH_RIGHT_SERVO_CHANNEL  8

// Lid MG996R on PCA9685 channel 0.
// Increase/decrease these if the lid does not fully close/open mechanically.
#define LID_CLOSED_ANGLE 0
#define LID_OPEN_ANGLE   -90

// Lid motion speed.
// Bigger step = faster but less smooth. Bigger delay = slower and gentler.
#define LID_SWEEP_STEP_DEG 5
#define LID_SWEEP_DELAY_MS 25

// Left photo-booth/drop MG996R on PCA9685 channel 4.
// Hold = picture/classification position.
// Drop = final tilt to release the object into the slide.
#define PHOTO_BOOTH_LEFT_HOLD_ANGLE    10
#define PHOTO_BOOTH_LEFT_DROP_ANGLE     -40

// Right photo-booth/drop MG996R on PCA9685 channel 8.
// It should mirror channel 4, but it is independent for real-life calibration.
#define PHOTO_BOOTH_RIGHT_HOLD_ANGLE     -35
#define PHOTO_BOOTH_RIGHT_DROP_ANGLE      12

// Photo-booth/drop motion speed.
// Bigger step = faster but less smooth. Bigger delay = slower and gentler.
#define PHOTO_BOOTH_SWEEP_STEP_DEG 5
#define PHOTO_BOOTH_SWEEP_DELAY_MS 25

// Time held at the drop angle before the photo booth returns to hold position.
#define PHOTO_BOOTH_DROP_TIME_MS 2000

uint16_t globalFrequency;
uint8_t globalAddress;

/* ============================================================
   PIN DEFINITIONS
   ============================================================ */

#define POT_MODE_SELECTOR PA0
#define GAME_HIGH_SCORE_RESET_BUTTON PA1
#define STATS_COUNT_RESET_BUTTON     PA3

// PA2, PA4, PA5, PA6, and PA7 are currently unused after removing FC-51 sensors.

#define DRV_STEP   PB0
#define DRV_DIR    PB1
#define DRV_ENABLE PB2

#define LCD_D5 PB3
#define LCD_D6 PB4
#define LCD_D7 PB5

#define KW11_HOME PB6

#define LED_METAL     PC2
#define LED_ORGANIC   PC3
#define LED_PAPER     PC4
#define LED_PLASTIC   PC5
#define LED_BATTERIES PC6
#define LED_OTHER     PC7

#define UART_RX PD0
#define UART_TX PD1

#define HCSR04_ECHO PD2
#define HCSR04_TRIG PD3

#define BUZZER PD4

#define LCD_RS PD5
#define LCD_E  PD6
#define LCD_D4 PD7

/* ============================================================
   SYSTEM SETTINGS
   ============================================================ */

#define HAND_DETECT_CM 15
#define UART_BAUD_9600_8MHZ 51
#define OBJECT_DROP_WINDOW_MS 5000
#define OBJECT_DROP_WINDOW_SECONDS (OBJECT_DROP_WINDOW_MS / 1000)
#define RPI_RESPONSE_TIMEOUT_100MS 200

#define LCD_WIDTH 16

// User-facing LCD timing. These do not change servo/stepper motion timing.
#define LCD_QUICK_MESSAGE_MS 1200
#define LCD_READ_MESSAGE_MS 2000
#define LCD_PROMPT_MESSAGE_MS 3000
#define GAME_HIGH_SCORE_MESSAGE_MS 5000
#define GAME_FEEDBACK_MESSAGE_MS 4000

// Reset buttons must be held, not just tapped, to avoid accidental resets.
#define RESET_BUTTON_HOLD_MS 2000
#define RESET_BUTTON_POLL_MS 25

// NEMA/DRV8825 speed calibration copied from the working NEMA calibration file.
// Lower values make the disk rotate faster; higher values rotate slower with more torque margin.
#define STEPPER_STEP_HIGH_US 4000
#define STEPPER_STEP_LOW_US  4000

// Homing is intentionally slower so the KW11 trigger tab reaches the switch gently.
#define STEPPER_HOME_STEP_HIGH_US 7000
#define STEPPER_HOME_STEP_LOW_US  7000

// KW11 home switch on PB6 uses the internal pull-up: not pressed = HIGH, pressed = LOW.
#define KW11_ACTIVE_LOW 1
#define KW11_DEBOUNCE_READS 5

// Sector 0 is the KW11 home position. These measured positions now match the
// physical bin order: 0 other, 1 plastic, 2 paper/cardboard, 3 metal,
// 4 organic, 5 batteries.
#define STEPPER_OTHER_POSITION_STEPS     0
#define STEPPER_PLASTIC_POSITION_STEPS   75
#define STEPPER_PAPER_POSITION_STEPS     105
#define STEPPER_METAL_POSITION_STEPS     125
#define STEPPER_ORGANIC_POSITION_STEPS   155
#define STEPPER_BATTERIES_POSITION_STEPS 190

// Used for clockwise wrap calculations.
#define STEPPER_TOTAL_STEPS 588

// If the KW11 is not reached within this time, stop homing and assume the
// disk is already at the starting position so the mechanism does not grind.
#define STEPPER_HOMING_TIMEOUT_MS 5000UL
#define STEPPER_SECOND_HOMING_TIMEOUT_MS 2000UL
#define KW11_SECOND_HOME_DELAY_MS 500UL
#define KW11_AFTER_SECOND_HOME_DELAY_MS 1000UL
#define STEPPER_HOME_STEP_PERIOD_US ((uint32_t)STEPPER_HOME_STEP_HIGH_US + (uint32_t)STEPPER_HOME_STEP_LOW_US)
#define STEPPER_HOMING_TIMEOUT_STEPS ((uint16_t)((STEPPER_HOMING_TIMEOUT_MS * 1000UL) / STEPPER_HOME_STEP_PERIOD_US))
#define STEPPER_SECOND_HOMING_TIMEOUT_STEPS ((uint16_t)((STEPPER_SECOND_HOMING_TIMEOUT_MS * 1000UL) / STEPPER_HOME_STEP_PERIOD_US))

uint16_t currentDiskPositionSteps = 0;
uint8_t diskIsHomed = 0;

/* ============================================================
   EEPROM
   ============================================================ */

uint8_t EEMEM eepromHighScore;
uint16_t EEMEM eepromBinCounts[6];
uint8_t highScore = 0;
uint16_t binCounts[6];

/* ============================================================
   MODES AND CATEGORIES
   ============================================================ */

typedef enum {
    MODE_STATS = 0,
    MODE_FILTERING = 1,
    MODE_GAME = 2
} SystemMode;

typedef enum {
    CAT_OTHER = 0,
    CAT_METAL = 1,
    CAT_ORGANIC = 2,
    CAT_PAPER = 3,
    CAT_PLASTIC = 4,
    CAT_BATTERIES = 5
} WasteCategory;

typedef enum {
    CLASSIFICATION_OK = 0,
    CLASSIFICATION_NO_OBJECT = 1,
    CLASSIFICATION_TIMEOUT = 2
} ClassificationResult;

/* ============================================================
   FUNCTION PROTOTYPES
   ============================================================ */

void lcd_clear(void);
void lcd_boot_init(void);
void lcd_print(const char *text);
void lcd_print_padded(const char *text);
void lcd_show_two_lines(const char *line0, const char *line1);
void lcd_show_idle_mode(SystemMode mode);
void lcd_print_uint8(uint8_t value);
void lcd_print_uint16(uint16_t value);
void lcd_set_cursor(uint8_t row, uint8_t col);
void lcd_lid_open_countdown(void);

const char* mode_name(SystemMode mode);
const char* category_name(WasteCategory category);

void lid_open(void);
void lid_close(void);
void photo_booth_hold_position(void);
void photo_booth_capture_position(void);
void photo_booth_drop_position(void);
void workspace_light_on(void);
void workspace_light_off(void);

ClassificationResult run_vision_capture(WasteCategory *category);

void stats_increment_category(WasteCategory category);
void stats_reset_counts(void);
uint8_t high_score_reset_if_requested(void);
uint8_t stats_reset_if_requested(void);

void rotate_disk_to_category(WasteCategory category);
void return_disk_to_home(void);

void process_sorted_object(WasteCategory category);

void run_filtering_mode(void);
void run_game_mode(void);
void run_stats_mode(void);

/* ============================================================
   DELAY HELPER
   ============================================================ */

void delay_ms_variable(uint16_t ms)
{
    while (ms > 0) {
        _delay_ms(1);
        ms--;
    }
}

/* ============================================================
   I2C / TWI FUNCTIONS
   ============================================================ */

void i2c_init(void)
{
    TWSR &= ~((1 << TWPS1) | (1 << TWPS0));
    TWBR = ((F_CPU / F_I2C) - 16) / 2;
}

int8_t i2c_tx_start(bool mode)
{
    int8_t status = 0;

    masterMode = mode;

    TWCR |= (1 << TWINT) | (1 << TWSTA) | (1 << TWEN);

    while (!(TWCR & (1 << TWINT)));

    switch (TWSR & 0xF8) {
        case 0x08:
        case 0x10:
            status = TRANSMISSION_SUCCESS;
            break;

        default:
            status = TRANSMISSION_ERROR;
            break;
    }

    return status;
}

int8_t i2c_tx_address(uint8_t address)
{
    int8_t status = 0;

    TWDR = (address << 1) | masterMode;
    TWCR = (1 << TWINT) | (1 << TWEN);

    while (!(TWCR & (1 << TWINT)));

    if (masterMode == MASTER_TRANSMITTER) {
        switch (TWSR & 0xF8) {
            case 0x18:
                status = TRANSMISSION_SUCCESS;
                break;

            default:
                status = TRANSMISSION_ERROR;
                break;
        }
    } else {
        switch (TWSR & 0xF8) {
            case 0x40:
                status = TRANSMISSION_SUCCESS;
                break;

            default:
                status = TRANSMISSION_ERROR;
                break;
        }
    }

    return status;
}

int8_t i2c_tx_byte(uint8_t byteData)
{
    int8_t status = 0;

    TWDR = byteData;
    TWCR |= (1 << TWINT);

    while (!(TWCR & (1 << TWINT)));

    switch (TWSR & 0xF8) {
        case 0x28:
            status = TRANSMISSION_SUCCESS;
            break;

        default:
            status = TRANSMISSION_ERROR;
            break;
    }

    return status;
}

void i2c_tx_stop(void)
{
    TWCR |= (1 << TWINT) | (1 << TWSTO);

    while (TWCR & (1 << TWSTO));
}

/* ============================================================
   PCA9685 / SERVO FUNCTIONS
   ============================================================ */

void pca9685_init(uint8_t address, uint16_t freq)
{
    globalFrequency = freq;
    globalAddress = address;

    i2c_init();

    i2c_tx_start(MASTER_TRANSMITTER);
    i2c_tx_address(0x40 + address);
    i2c_tx_byte(0x00);
    i2c_tx_byte(0b00110001);
    i2c_tx_stop();

    _delay_ms(1);

    volatile uint8_t prescalar =
        (25000000 / ((float)4096 * freq * 0.92)) - 1;

    i2c_tx_start(MASTER_TRANSMITTER);
    i2c_tx_address(0x40 + address);
    i2c_tx_byte(0xFE);
    i2c_tx_byte(prescalar);
    i2c_tx_stop();

    _delay_ms(1);

    i2c_tx_start(MASTER_TRANSMITTER);
    i2c_tx_address(0x40 + address);
    i2c_tx_byte(0x00);
    i2c_tx_byte(0b10100001);
    i2c_tx_stop();

    _delay_ms(1);

    i2c_tx_start(MASTER_TRANSMITTER);
    i2c_tx_address(0x40 + address);
    i2c_tx_byte(0x01);
    i2c_tx_byte(0b00000100);
    i2c_tx_stop();
}

void pca9685_servo(uint8_t servoNum, float angle)
{
    if (angle > 90) {
        angle = 90;
    } else if (angle < -90) {
        angle = -90;
    }

    uint16_t pulse_us =
        NEUTRAL_PULSE +
        angle * ((float)(MAX_PULSE - MIN_PULSE) / (2 * MAX_ANGLE));

    uint16_t period_us = (float)1000000 / globalFrequency;
    uint16_t count = ((float)pulse_us / period_us) * 4096;

    uint8_t offLowCmnd = count;
    uint8_t offHighCmnd = count >> 8;

    i2c_tx_start(MASTER_TRANSMITTER);
    i2c_tx_address(0x40 + globalAddress);
    i2c_tx_byte(SERVO0 + (4 * servoNum));
    i2c_tx_byte(0x00);
    i2c_tx_byte(0x00);
    i2c_tx_byte(offLowCmnd);
    i2c_tx_byte(offHighCmnd);
    i2c_tx_stop();
}

uint8_t abs_i16(int16_t value)
{
    if (value < 0) {
        value = -value;
    }

    if (value > 255) {
        return 255;
    }

    return (uint8_t)value;
}

void servo_sweep_calibrated(
    uint8_t channel,
    int8_t fromAngle,
    int8_t toAngle,
    uint8_t stepDeg,
    uint16_t stepDelayMs
)
{
#if !SERVO_SYSTEM_ENABLED
    (void)channel;
    (void)fromAngle;
    (void)toAngle;
    (void)stepDeg;
    (void)stepDelayMs;
    return;
#else
    int16_t angle = fromAngle;
    int8_t direction;

    if (stepDeg == 0) {
        stepDeg = 1;
    }

    direction = (fromAngle < toAngle) ? 1 : -1;

    while (
        (direction > 0 && angle < toAngle) ||
        (direction < 0 && angle > toAngle)
    ) {
        pca9685_servo(channel, angle);
        delay_ms_variable(stepDelayMs);
        angle += direction * stepDeg;
    }

    pca9685_servo(channel, toAngle);
    delay_ms_variable(stepDelayMs);
#endif
}

void photo_booth_set_pair(int8_t leftAngle, int8_t rightAngle)
{
#if !SERVO_SYSTEM_ENABLED
    (void)leftAngle;
    (void)rightAngle;
    return;
#else
    pca9685_servo(PHOTO_BOOTH_LEFT_SERVO_CHANNEL, leftAngle);
    pca9685_servo(PHOTO_BOOTH_RIGHT_SERVO_CHANNEL, rightAngle);
#endif
}

void photo_booth_sweep_pair(
    int8_t fromLeftAngle,
    int8_t toLeftAngle,
    int8_t fromRightAngle,
    int8_t toRightAngle
)
{
    uint8_t leftTravel = abs_i16((int16_t)toLeftAngle - fromLeftAngle);
    uint8_t rightTravel = abs_i16((int16_t)toRightAngle - fromRightAngle);
    uint8_t maxTravel = (leftTravel > rightTravel) ? leftTravel : rightTravel;
    uint8_t steps;

    if (PHOTO_BOOTH_SWEEP_STEP_DEG == 0) {
        steps = maxTravel;
    } else {
        steps = maxTravel / PHOTO_BOOTH_SWEEP_STEP_DEG;
    }

    if (steps == 0) {
        steps = 1;
    }

    for (uint8_t i = 0; i <= steps; i++) {
        int8_t leftAngle =
            fromLeftAngle +
            (((int16_t)toLeftAngle - fromLeftAngle) * i) / steps;

        int8_t rightAngle =
            fromRightAngle +
            (((int16_t)toRightAngle - fromRightAngle) * i) / steps;

        photo_booth_set_pair(leftAngle, rightAngle);
        delay_ms_variable(PHOTO_BOOTH_SWEEP_DELAY_MS);
    }
}

void lid_open(void)
{
#if !SERVO_SYSTEM_ENABLED
    lcd_clear();
    lcd_print("Lid skipped");
    lcd_set_cursor(1, 0);
    lcd_print("No PCA9685");
    _delay_ms(500);
#else
    servo_sweep_calibrated(
        LID_SERVO_CHANNEL,
        LID_CLOSED_ANGLE,
        LID_OPEN_ANGLE,
        LID_SWEEP_STEP_DEG,
        LID_SWEEP_DELAY_MS
    );
#endif
}

void lid_close(void)
{
#if !SERVO_SYSTEM_ENABLED
    lcd_clear();
    lcd_print("Lid close skip");
    lcd_set_cursor(1, 0);
    lcd_print("No PCA9685");
    _delay_ms(500);
#else
    servo_sweep_calibrated(
        LID_SERVO_CHANNEL,
        LID_OPEN_ANGLE,
        LID_CLOSED_ANGLE,
        LID_SWEEP_STEP_DEG,
        LID_SWEEP_DELAY_MS
    );
#endif
}

void photo_booth_hold_position(void)
{
#if !SERVO_SYSTEM_ENABLED
    return;
#else
    photo_booth_set_pair(
        PHOTO_BOOTH_LEFT_HOLD_ANGLE,
        PHOTO_BOOTH_RIGHT_HOLD_ANGLE
    );
#endif
}

void photo_booth_capture_position(void)
{
#if !SERVO_SYSTEM_ENABLED
    lcd_clear();
    lcd_print("Photo booth");
    lcd_set_cursor(1, 0);
    lcd_print("Servo skipped");
    _delay_ms(500);
#else
    photo_booth_set_pair(
        PHOTO_BOOTH_LEFT_HOLD_ANGLE,
        PHOTO_BOOTH_RIGHT_HOLD_ANGLE
    );
#endif
}

void photo_booth_drop_position(void)
{
    lcd_clear();
    lcd_print("Dropping waste");
    lcd_set_cursor(1, 0);
#if !SERVO_SYSTEM_ENABLED
    lcd_print("Servo skipped");
    _delay_ms(1000);
#else
    lcd_print("To slide");

    photo_booth_sweep_pair(
        PHOTO_BOOTH_LEFT_HOLD_ANGLE,
        PHOTO_BOOTH_LEFT_DROP_ANGLE,
        PHOTO_BOOTH_RIGHT_HOLD_ANGLE,
        PHOTO_BOOTH_RIGHT_DROP_ANGLE
    );
    delay_ms_variable(PHOTO_BOOTH_DROP_TIME_MS);

    photo_booth_sweep_pair(
        PHOTO_BOOTH_LEFT_DROP_ANGLE,
        PHOTO_BOOTH_LEFT_HOLD_ANGLE,
        PHOTO_BOOTH_RIGHT_DROP_ANGLE,
        PHOTO_BOOTH_RIGHT_HOLD_ANGLE
    );
#endif
}

/* ============================================================
   LCD FUNCTIONS
   ============================================================ */

void lcd_pulse_enable(void)
{
    PORTD |= (1 << LCD_E);
    _delay_us(1);
    PORTD &= ~(1 << LCD_E);
    _delay_us(100);
}

void lcd_write_nibble(uint8_t nibble)
{
    if (nibble & 0x01) PORTD |= (1 << LCD_D4);
    else PORTD &= ~(1 << LCD_D4);

    if (nibble & 0x02) PORTB |= (1 << LCD_D5);
    else PORTB &= ~(1 << LCD_D5);

    if (nibble & 0x04) PORTB |= (1 << LCD_D6);
    else PORTB &= ~(1 << LCD_D6);

    if (nibble & 0x08) PORTB |= (1 << LCD_D7);
    else PORTB &= ~(1 << LCD_D7);

    lcd_pulse_enable();
}

void lcd_send(uint8_t value, uint8_t rs)
{
    if (rs) PORTD |= (1 << LCD_RS);
    else PORTD &= ~(1 << LCD_RS);

    lcd_write_nibble(value >> 4);
    lcd_write_nibble(value & 0x0F);
}

void lcd_command(uint8_t command)
{
    lcd_send(command, 0);
    _delay_ms(2);
}

void lcd_data(uint8_t data)
{
    lcd_send(data, 1);
}

void lcd_init(void)
{
    _delay_ms(120);

    PORTD &= ~(1 << LCD_RS);
    PORTD &= ~(1 << LCD_E);

    lcd_write_nibble(0x03);
    _delay_ms(5);

    lcd_write_nibble(0x03);
    _delay_us(150);

    lcd_write_nibble(0x03);
    _delay_us(150);

    lcd_write_nibble(0x02);

    lcd_command(0x28);
    lcd_command(0x0C);
    lcd_command(0x06);
    lcd_command(0x01);
}

void lcd_boot_init(void)
{
    lcd_init();
    _delay_ms(50);
    lcd_init();
    lcd_show_two_lines("", "");
}

void lcd_clear(void)
{
    lcd_command(0x01);
    _delay_ms(2);
}

void lcd_set_cursor(uint8_t row, uint8_t col)
{
    uint8_t address = (row == 0) ? col : (0x40 + col);
    lcd_command(0x80 | address);
}

void lcd_print(const char *text)
{
    while (*text) {
        lcd_data(*text++);
    }
}

void lcd_print_padded(const char *text)
{
    uint8_t col = 0;

    while (*text && col < LCD_WIDTH) {
        lcd_data(*text++);
        col++;
    }

    while (col < LCD_WIDTH) {
        lcd_data(' ');
        col++;
    }
}

void lcd_show_two_lines(const char *line0, const char *line1)
{
    lcd_clear();
    lcd_set_cursor(0, 0);
    lcd_print_padded(line0);
    lcd_set_cursor(1, 0);
    lcd_print_padded(line1);
}

void lcd_show_idle_mode(SystemMode mode)
{
    lcd_boot_init();
    lcd_show_two_lines("Select mode:", mode_name(mode));
}

void lcd_print_uint8(uint8_t value)
{
    if (value >= 100) {
        lcd_data('0' + (value / 100));
        value %= 100;
        lcd_data('0' + (value / 10));
        lcd_data('0' + (value % 10));
    } else if (value >= 10) {
        lcd_data('0' + (value / 10));
        lcd_data('0' + (value % 10));
    } else {
        lcd_data('0' + value);
    }
}

void lcd_print_uint16(uint16_t value)
{
    uint16_t divisor = 10000;
    uint8_t started = 0;

    while (divisor > 0) {
        uint8_t digit = value / divisor;

        if (digit != 0 || started || divisor == 1) {
            lcd_data('0' + digit);
            started = 1;
        }

        value %= divisor;
        divisor /= 10;
    }
}

void lcd_lid_open_countdown(void)
{
    for (uint8_t seconds = OBJECT_DROP_WINDOW_SECONDS; seconds > 0; seconds--) {
        lcd_clear();
        lcd_print("Drop object");
        lcd_set_cursor(1, 0);
        lcd_print("Close in ");
        lcd_print_uint8(seconds);
        lcd_print(" sec");

        delay_ms_variable(1000);
    }
}

/* ============================================================
   UART FUNCTIONS
   ============================================================ */

void uart_init(void)
{
    UBRRH = 0;
    UBRRL = UART_BAUD_9600_8MHZ;

    UCSRB = (1 << RXEN) | (1 << TXEN);
    UCSRC = (1 << URSEL) | (1 << UCSZ1) | (1 << UCSZ0);
}

void uart_send_char(char c)
{
    while (!(UCSRA & (1 << UDRE)));
    UDR = c;
}

void uart_send_string(const char *text)
{
    while (*text) {
        uart_send_char(*text++);
    }
}

uint8_t uart_char_available(void)
{
    return (UCSRA & (1 << RXC));
}

char uart_receive_char(void)
{
    while (!uart_char_available());
    return UDR;
}

uint8_t uart_read_line_timeout(char *buffer, uint8_t maxLen, uint16_t timeout100ms)
{
    uint8_t index = 0;

    if (maxLen == 0) {
        return 0;
    }

    while (timeout100ms > 0) {
        for (uint8_t tick = 0; tick < 100; tick++) {
            if (uart_char_available()) {
                char c = uart_receive_char();

                if (c == '\r') {
                    continue;
                }

                if (c == '\n') {
                    buffer[index] = '\0';
                    return (index > 0);
                }

                if (index < (maxLen - 1)) {
                    buffer[index++] = c;
                }
            }

            _delay_ms(1);
        }

        timeout100ms--;
    }

    buffer[index] = '\0';
    return (index > 0);
}

void uart_flush_rx(void)
{
    while (uart_char_available()) {
        (void)UDR;
    }
}

/* ============================================================
   ADC / POTENTIOMETER FUNCTIONS
   ============================================================ */
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
int main(void)
{
    SystemMode currentMode;
    SystemMode lockedMode;
    SystemMode displayedMode = (SystemMode)255;
    uint8_t forceIdleRedraw = 1;

    hardware_init();

    while (1) {
        currentMode = read_mode_from_pot();

        if (forceIdleRedraw || currentMode != displayedMode) {
            lcd_show_idle_mode(currentMode);
            displayedMode = currentMode;
            forceIdleRedraw = 0;
        }

        for (uint8_t i = 0; i < 10; i++) {
            if (hand_detected()) {
                lockedMode = read_mode_from_pot();

                lcd_show_two_lines("Locked:", mode_name(lockedMode));
                _delay_ms(LCD_QUICK_MESSAGE_MS);

                if (lockedMode == MODE_FILTERING) {
                    run_filtering_mode();
                } else if (lockedMode == MODE_GAME) {
                    run_game_mode();
                } else if (lockedMode == MODE_STATS) {
                    run_stats_mode();
                }

                forceIdleRedraw = 1;
                displayedMode = (SystemMode)255;
            }

            _delay_ms(100);
        }
    }

    return 0;
}

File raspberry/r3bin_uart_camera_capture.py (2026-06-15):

from pathlib import Path
import time
import cv2
import numpy as np
import serial

try:
    from ai_edge_litert.interpreter import Interpreter
except ImportError:
    from tflite_runtime.interpreter import Interpreter

BASE = Path.home() / "r3bin"
MODEL_PATH = BASE / "model" / "model_unquant.tflite"
LABELS_PATH = BASE / "model" / "labels.txt"
CAPTURE_DIR = BASE / "captures"

SERIAL_PORT = "/dev/serial0"
BAUD_RATE = 9600
CONFIDENCE_MIN = 0.60

CAPTURE_DIR.mkdir(parents=True, exist_ok=True)


def load_labels(path):
    labels = []

    with open(path, "r", encoding="utf-8") as f:
        for line in f:
            text = line.strip()

            if not text:
                continue

            parts = text.split(maxsplit=1)

            if len(parts) == 2 and parts[0].isdigit():
                text = parts[1]

            labels.append(text)

    return labels


def normalize_label(label):
    text = label.strip().lower()
    text = text.replace("-", "_").replace(" ", "_")

    if "metal" in text:
        return "METAL"

    if "organic" in text:
        return "ORGANIC"

    if "paper" in text or "cardboard" in text or "carboard" in text or "carton" in text:
        return "PAPER"

    if "plastic" in text:
        return "PLASTIC"

    if "batter" in text or "pila" in text:
        return "BATTERIES"

    if "no_object" in text or "empty" in text or "none" in text:
        return "NO_OBJECT"

    return "OTHER"


def prepare_input(frame, width, height, input_dtype):
    rgb = cv2.cvtColor(frame, cv2.COLOR_BGR2RGB)
    resized = cv2.resize(rgb, (width, height))
    input_data = np.expand_dims(resized, axis=0)

    if input_dtype == np.float32:
        input_data = input_data.astype(np.float32)
        input_data = (input_data / 127.5) - 1.0
    else:
        input_data = input_data.astype(input_dtype)

    return input_data


labels = load_labels(LABELS_PATH)

interpreter = Interpreter(model_path=str(MODEL_PATH))
interpreter.allocate_tensors()

input_details = interpreter.get_input_details()
output_details = interpreter.get_output_details()

input_shape = input_details[0]["shape"]
height = input_shape[1]
width = input_shape[2]
input_dtype = input_details[0]["dtype"]


def classify_once():
    cap = cv2.VideoCapture(0)

    if not cap.isOpened():
        print("Camera error")
        return "NO_OBJECT"

    time.sleep(0.4)

    frame = None

    for _ in range(6):
        ok, captured_frame = cap.read()

        if ok:
            frame = captured_frame

        time.sleep(0.08)

    cap.release()

    if frame is None:
        print("No frame")
        return "NO_OBJECT"

    timestamp = time.strftime("%Y%m%d_%H%M%S")
    image_path = CAPTURE_DIR / f"capture_{timestamp}.jpg"
    cv2.imwrite(str(image_path), frame)

    input_data = prepare_input(frame, width, height, input_dtype)

    interpreter.set_tensor(input_details[0]["index"], input_data)
    interpreter.invoke()

    output = interpreter.get_tensor(output_details[0]["index"])[0]
    best_index = int(np.argmax(output))
    confidence = float(output[best_index])

    raw_label = labels[best_index]
    category = normalize_label(raw_label)

    if confidence < CONFIDENCE_MIN and category != "NO_OBJECT":
        category = "OTHER"

    print(f"Photo: {image_path.name}")
    print(f"Prediction: {raw_label} -> {category} ({confidence:.2f})")

    return category


def main():
    print("R3Bin Raspberry vision ready")
    print("Waiting for CAPTURE...")

    ser = serial.Serial(SERIAL_PORT, BAUD_RATE, timeout=0.2)
    time.sleep(2)

    while True:
        line = ser.readline().decode("utf-8", errors="ignore").strip()

        if not line:
            continue

        print(f"ATmega says: {line}")

        if line == "CAPTURE":
            category = classify_once()
            response = category + "\n"

            ser.write(response.encode("utf-8"))
            ser.flush()

            print(f"Sent: {category}")
            print("Waiting for CAPTURE...")


if __name__ == "__main__":
    main()

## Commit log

2026-06-15 Initial R3Bin portfolio repository
    [HC-SR04-Sensor.3mf, HC-SR04-Sensor.stl, HC-SR04-Sensor.stp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]
2026-06-15 Replace prototype hero and internal images
